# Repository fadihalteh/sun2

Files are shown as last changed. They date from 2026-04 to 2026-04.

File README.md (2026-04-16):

# SunLock Lab Solar Stewart Tracker

<p align="center">
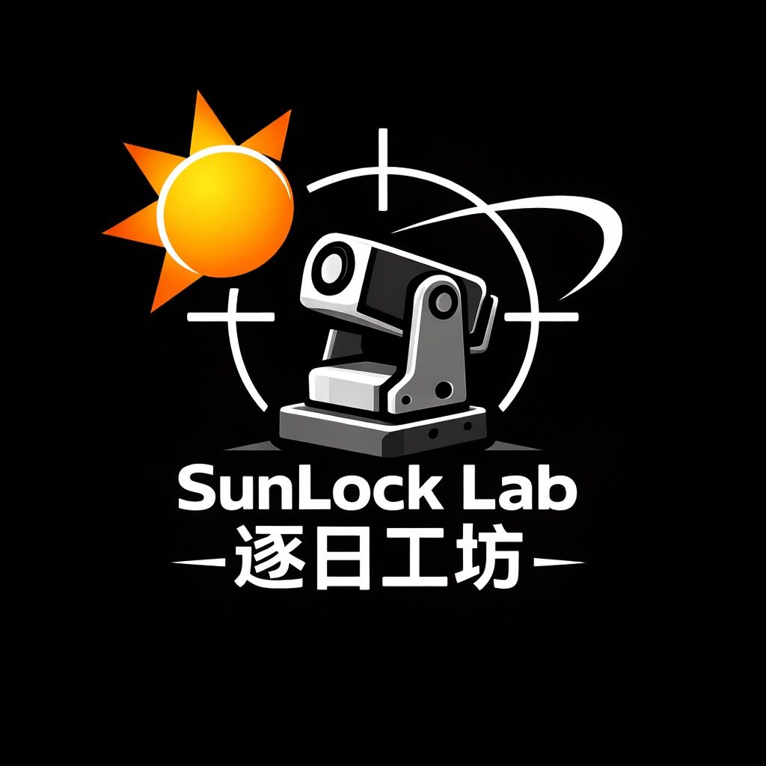
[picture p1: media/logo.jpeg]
SunLock Lab Solar Stewart Tracker
  
</p>
circuitff

https://github.com/user-attachments/assets/e373fa9c-2d9f-4f3f-8f36-7be25adaffa7

[https://www.youtube.com/shorts/J-tgFS92vjE](url)

Real-time embedded **C++17** software for solar tracking using a **3-RRS Stewart-type parallel mechanism** on **Raspberry Pi / Linux**.

This project implements an event-driven pipeline in which camera frames are delivered through callbacks, processed by vision and control modules, converted into platform motion through inverse kinematics, and safely applied to three actuators through a hardware abstraction layer. The runtime is structured around blocking waits, callback-driven stage transitions, bounded queues, and modular components so the software remains responsive, maintainable, testable, and reproducible.

<p align="center">
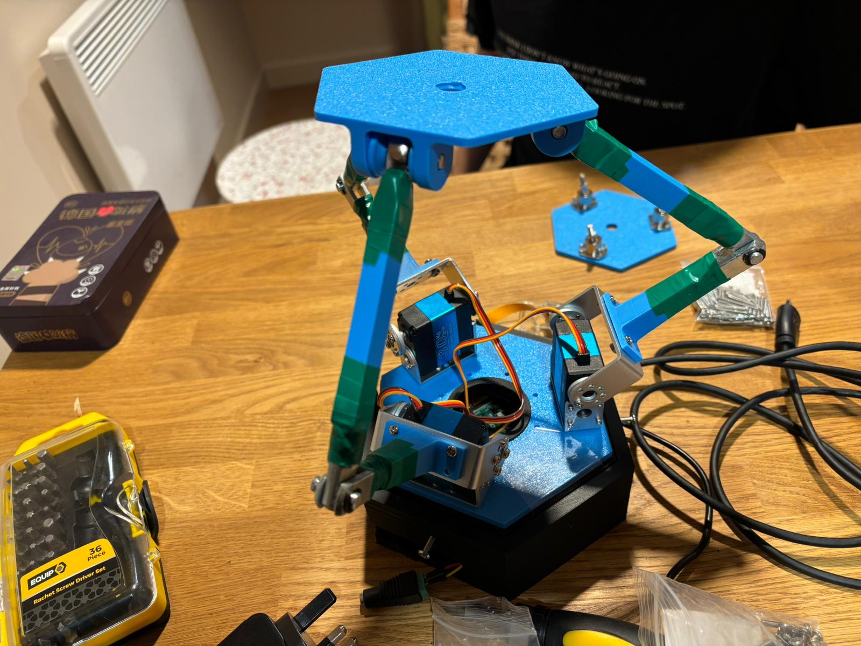
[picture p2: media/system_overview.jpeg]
System Overview
  
</p>
<p align="center">
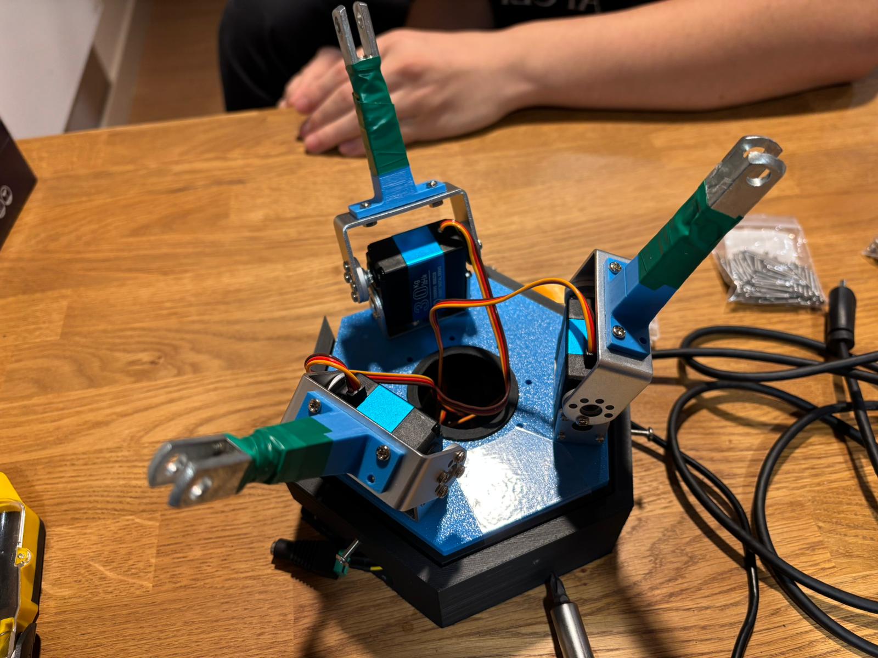
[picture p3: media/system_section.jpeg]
System Section
  
</p>
<p align="center">
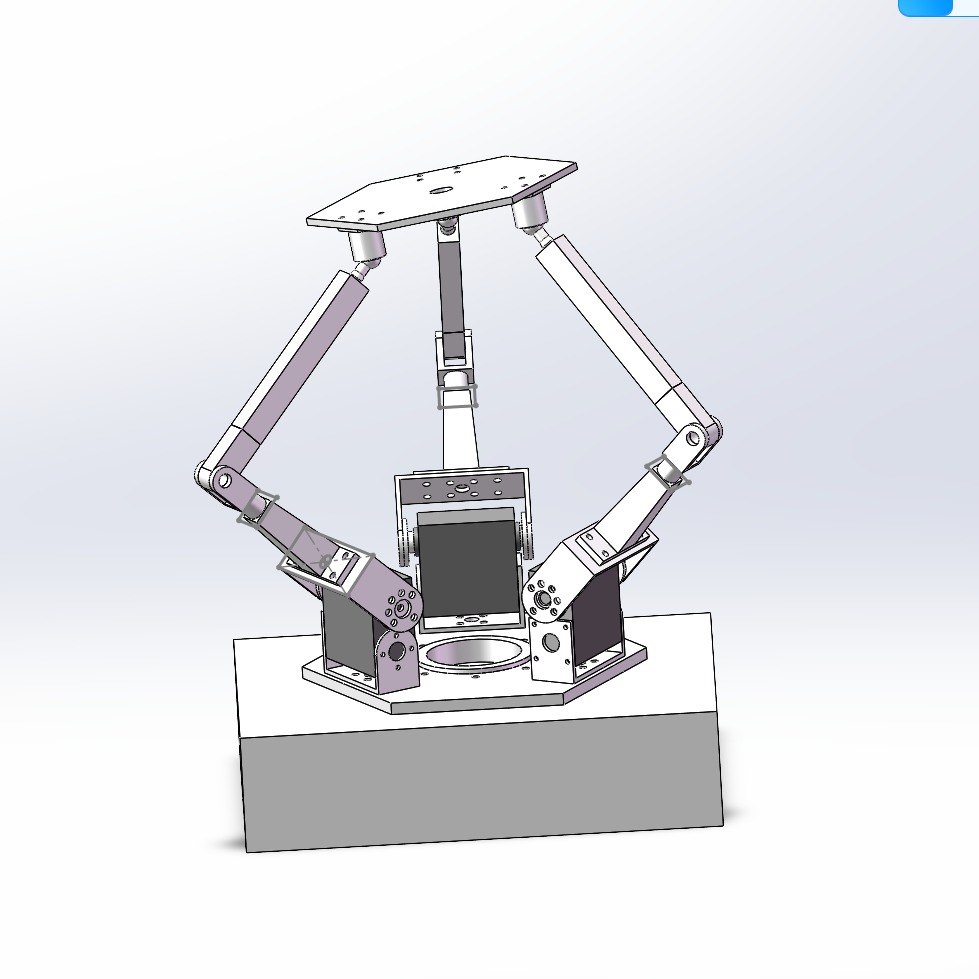
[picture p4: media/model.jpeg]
System Model
  
</p>

---
<p align="center">
  <strong>Explore the full generated developer reference, architecture pages, and API documentation.</strong><br>
  📘 <a href="https://real-time-stewart-solar-tracker.github.io/Solar-Stewart-Tracker/">
    Doxygen Documentation
  </a>
</p>

---
## Table of Contents

- [Social Media](#social-media)
- [Project Overview](#project-overview)
- [Project Management](#project-management)
- [Key Features](#key-features)
- [System Architecture](#system-architecture)
- [Sequence Diagram](#sequence-diagram)
- [Circuit Diagram](#circuit-diagram)
- [Repository Structure](#repository-structure)
- [Bill of Materials](#bill-of-materials)
- [Dependencies](#dependencies)
- [Cloning](#cloning)
- [Building](#building)
- [Running](#running)
- [Running Tests](#running-tests)
- [Realtime Evidence](#realtime-evidence)
- [Documentation](#documentation)
- [Authors and Contributions](#authors-and-contributions)
- [Acknowledgements](#acknowledgements)
- [License](#license)
- [Future Work](#future-work)
- [Last Updated](#last-updated)

---

## Social Media

We actively document the development, testing, and realtime performance of the **Solar Stewart Tracker** to promote transparency, reproducibility, and engagement with the engineering community.

📌 **TikTok (Primary Platform)**  
https://www.tiktok.com/@sunlock.lab_2

Content includes:

- realtime tracking demonstrations
- hardware setup and wiring
- development progress updates
- testing and debugging clips

---

## Project Overview

The **Solar Stewart Tracker** is a Linux userspace realtime embedded system that:

- acquires camera frames from a camera backend
- detects the sun position using image processing
- computes tracking corrections
- converts desired motion into **3-RRS inverse kinematics**
- applies safety shaping before actuation
- drives three servo outputs through a PCA9685 PWM controller

The design goal is not only functional tracking, but tracking implemented in a way that is:

- **event-driven**
- **responsive**
- **modular**
- **testable**
- **reproducible**
- **safe for hardware control**

The main software path is:

**Camera → SunTracker → Controller → ManualImuCoordinator → Kinematics3RRS → ActuatorManager → ServoDriver**

---

## Project Management

Development was tracked through GitHub issues, milestones, branches, pull requests, and tagged releases.

See:
- Issues for feature planning and bug tracking
- Milestones for delivery stages
- Pull requests for reviewed changes
- Releases 
---

## Key Features

- **Realtime event-driven processing**
  - callback-based frame delivery
  - blocking worker threads
  - no busy-wait control loop in the processing pipeline
  - no sleep-based timing in the control path

- **Modular C++17 architecture**
  - `SystemManager` orchestrates the runtime pipeline
  - hardware-facing and processing modules are separated by clear interfaces
  - optional backends and UI layers do not change the core architecture

- **Multiple build and use modes**
  - Linux / Raspberry Pi execution
  - software-only path with simulated camera input
  - headless CLI application
  - optional Qt GUI target

- **Safety-oriented actuation path**
  - actuator clamping
  - optional slew/rate limiting
  - neutral / park behaviour on start and stop
  - explicit handling of low-confidence tracking conditions
  - fault-driven suppression of invalid actuation commands

- **Engineering evidence built into the repository**
  - CMake-based build
  - CTest-integrated automated tests
  - latency measurement exported to artefacts
  - Doxygen-ready source tree
  - structured repository layout by subsystem

---

## System Architecture

<p align="center">
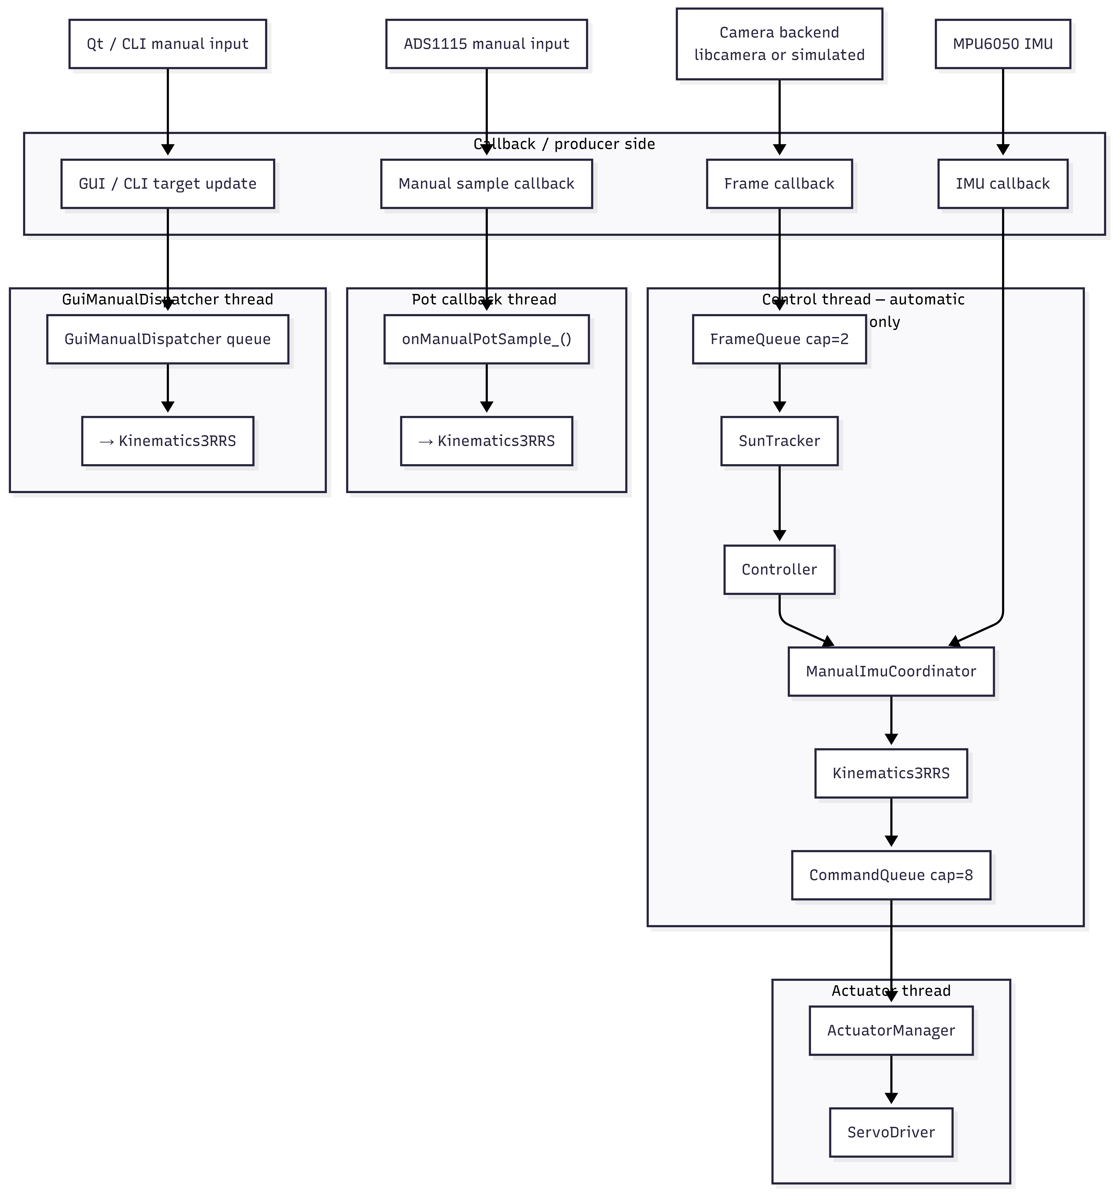
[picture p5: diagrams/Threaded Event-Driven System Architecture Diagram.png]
System Architecture
  
</p>

The repository is organised around a staged runtime pipeline.

### Core Modules

- **ICamera**  
  Abstract camera interface used by the system.

- **LibcameraPublisher**  
  Raspberry Pi / Linux camera backend when `libcamera` is available.

- **SimulatedPublisher**  
  Fallback or simulation camera backend.

- **SystemManager**  
  Top-level orchestrator for state, queues, callbacks, and worker threads.

- **SunTracker**  
  Vision module that finds the bright target and estimates sun position.

- **Controller**  
  Converts tracking error into platform tilt/pan setpoints.

- **ManualImuCoordinator**  
  Coordinates manual input ownership and optional IMU-based correction.

- **Kinematics3RRS**  
  Converts platform setpoints into actuator-space commands.

- **ActuatorManager**  
  Safety shaping layer for command limiting.

- **ServoDriver**  
  Final actuator output layer.

- **LatencyMonitor**  
  Measures timing across the userspace pipeline.

### Threading Model

The runtime is structured as a **multi-threaded, event-driven system** where **blocking I/O is used to wake up threads**, and callbacks propagate data through the processing pipeline.

Separate execution contexts are used for:

- **camera / backend context**: frame acquisition and callback delivery
- **control thread**: vision, control, coordination, and kinematics
- **actuator thread**: safety filtering and output application
- **main / event loop**: application lifecycle and optional UI / event handling

### Queue Policy

Inter-stage communication uses bounded queues with a freshest-data policy:

- **frame queue capacity:** 2
- **command queue capacity:** 8

Both queues use `push_latest(...)`. When a queue is full, the oldest item is discarded before the newest item is inserted. This bounds memory use, prevents unbounded backlog, and keeps the control path biased toward current data rather than stale queued work.

---

## Sequence Diagram

```mermaid
sequenceDiagram
    actor User
    participant Cam as Camera
    participant SM as SystemManager
    participant BC as BackendCoordinator
    participant GMD as GuiManualDispatcher
    participant FQ as FrameQueue
    participant CT as Control thread
    participant ST as SunTracker
    participant C as Controller
    participant MIC as ManualImuCoordinator
    participant K as Kinematics3RRS
    participant CQ as CommandQueue
    participant AT as Actuator thread
    participant AM as ActuatorManager
    participant SD as ServoDriver
    participant ADS as ADS1115
    participant IMU as MPU6050
    participant LM as LatencyMonitor

    User->>SM: start()
    SM->>SD: start()
    SM->>GMD: start()
    SM->>BC: start()
    Note over BC: starts ADS1115 and IMU backends
    SM->>Cam: start()
    SM->>SM: state = SEARCHING / MANUAL

    IMU-->>SM: imu sample callback
    SM->>MIC: updateImuSample(sample)

    rect rgb(245,245,255)
    Note over Cam,SD: Automatic path — control thread only
    Cam-->>SM: FrameEvent callback
    SM->>LM: onCapture(...)
    SM->>FQ: push_latest(frame)

    CT->>FQ: wait_pop()
    FQ-->>CT: FrameEvent
    CT->>ST: onFrame(frame)
    ST-->>CT: SunEstimate callback
    CT->>LM: onEstimate(...)
    CT->>C: onEstimate(estimate)
    C-->>CT: PlatformSetpoint callback
    CT->>LM: onControl(...)
    CT->>MIC: applyImuCorrection(setpoint)
    MIC-->>CT: corrected setpoint
    CT->>K: onSetpoint(setpoint)
    K-->>CT: ActuatorCommand callback
    CT->>CQ: push_latest(command)
    end

    rect rgb(245,255,245)
    Note over ADS,K: Pot manual path — ADS1115 callback thread, independent of camera frames
    ADS-->>SM: ManualPotSample callback
    SM->>MIC: buildManualSetpointFromPot(...)
    MIC-->>SM: PlatformSetpoint
    SM->>MIC: applyImuCorrection(sp)
    MIC-->>SM: corrected setpoint
    SM->>LM: onControl(...)
    SM->>K: onSetpoint(setpoint)
    K-->>SM: ActuatorCommand callback
    SM->>CQ: push_latest(command)
    end

    rect rgb(255,250,240)
    Note over User,K: GUI manual path — GuiManualDispatcher thread, independent of camera frames
    User->>SM: enterManual()
    SM->>SM: state = MANUAL

    User->>SM: setManualSetpoint(tilt, pan)
    SM->>GMD: setSetpoint(tilt, pan)
    Note over GMD: push_latest wakes thread immediately
    GMD->>MIC: buildManualSetpointFromGui(...)
    MIC-->>GMD: PlatformSetpoint
    GMD->>MIC: applyImuCorrection(sp)
    MIC-->>GMD: corrected setpoint
    GMD->>LM: onControl(...)
    GMD->>K: onSetpoint(setpoint)
    K-->>GMD: ActuatorCommand callback
    GMD->>CQ: push_latest(command)

    User->>SM: exitManual()
    SM->>SM: state = SEARCHING
    end

    rect rgb(240,240,240)
    Note over CQ,SD: Actuator path — actuator thread
    AT->>CQ: wait_pop()
    CQ-->>AT: ActuatorCommand
    AT->>AM: onCommand(command)
    AM-->>AT: safe command callback
    AT->>LM: onActuate(...)
    AT->>SD: apply(command)
    end

    User->>SM: stop()
    SM->>Cam: stop()
    SM->>BC: stop()
    SM->>GMD: stop()
    SM->>SD: stop()
    SM->>SM: state = IDLE
```

---

## Circuit Diagram

<p align="center">
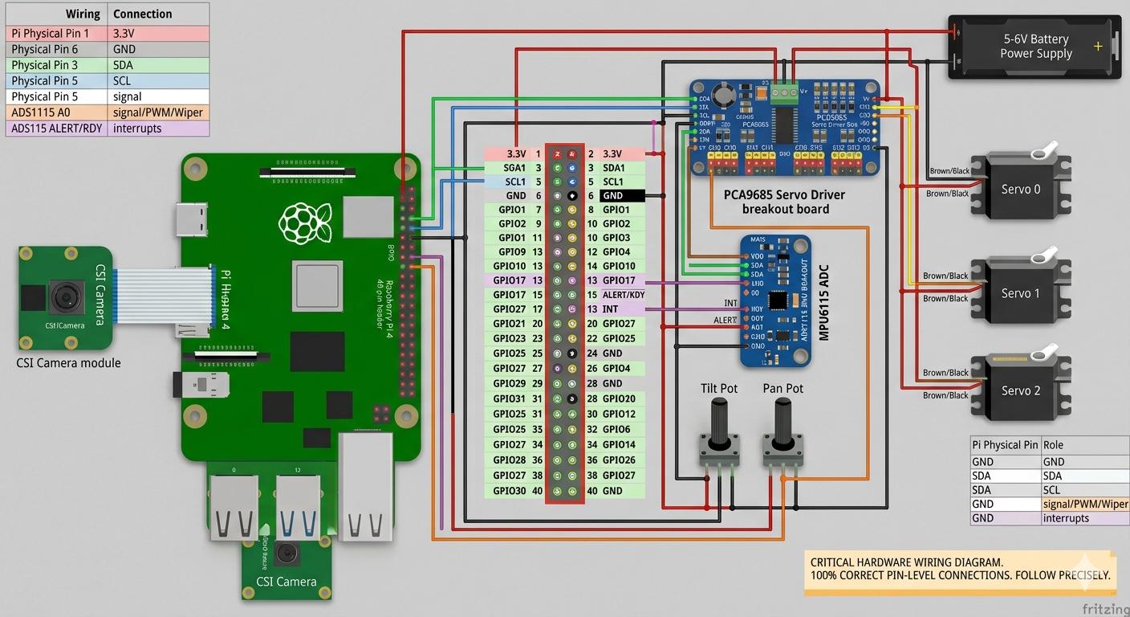
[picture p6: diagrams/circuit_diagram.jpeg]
Circuit Diagram
  
</p>

The hardware setup connects:

- camera through a libcamera-compatible interface
- PCA9685 PWM driver over I2C
- ADS1115 over I2C for manual input
- MPU6050 over I2C for feedback
- three servo motors
- Raspberry Pi acting as the central controller

The PCA9685 generates PWM signals for the servos, while I2C provides communication between the Raspberry Pi, the manual-input ADC, the IMU, and the actuator driver layer.

> **Exact connection mapping:** see [`docs/hardware_connections.md`](docs/hardware_connections.md).  
> This document is the source of truth for physical Raspberry Pi pin numbers, I2C wiring, GPIO interrupt pins, servo channel assignments, potentiometer wiring, and shared-ground requirements.

---

## Repository Structure

```text
Solar-Stewart-Tracker/
├── .github/
│   └── workflows/
├── artefacts/
├── external/
│   ├── libcamera2opencv/
│   └── libgpiod_event_demo/
├── scripts/
├── src/
│   ├── actuators/
│   │   └── tests/
│   ├── app/
│   ├── common/
│   │   └── tests/
│   ├── control/
│   │   └── tests/
│   ├── hal/
│   │   └── tests/
│   ├── qt/
│   ├── sensors/
│   │   └── tests/
│   ├── system/
│   │   └── tests/
│   ├── tests/
│   │   └── support/
│   └── vision/
│       └── tests/
├── CMakeLists.txt
├── CONTRIBUTING.md
├── Doxyfile
└── LICENSE
```

---

## Bill of Materials

### Controller

| Component | Quantity | Cost (£) |
|---|---:|---:|
| Raspberry Pi 5 (8GB) | 1 | 80.00 |

### Sensors and Vision

| Component | Quantity | Cost (£) |
|---|---:|---:|
| IMX219 Camera Module | 1 | 25.00 |

### Actuation and Drive

| Component | Quantity | Cost (£) |
|---|---:|---:|
| PCA9685 PWM Driver | 1 | 12.00 |
| High-Torque Servo (RDS3230 or equivalent) | 3 | 45.00 |
| External 5–6V High-Current Supply | 1 | 20.00 |

### Mechanical and Supporting Components

| Component | Quantity | Cost (£) |
|---|---:|---:|
| Breadboard and Wiring Set | 1 | 10.00 |
| Structural Frame / 3D Printed Parts | 1 | 15.00 |
| Fasteners and Mounts | Assorted | 10.00 |

**Grand Total: £217.00**

---

## Dependencies

### Mandatory

- CMake 3.16 or newer
- C++17 compiler
  - GCC
  - Clang
  - MSVC

### Optional

- **libcamera**  
  Enables the Raspberry Pi camera backend.

- **Qt5 Widgets / Charts**  
  Enables the optional Qt GUI target.

- **OpenCV**  
  Enables optional image-conversion and viewer support where available.

### Linux Packages

#### Minimal build tools

```bash
sudo apt update
sudo apt install -y build-essential cmake git pkg-config
```

#### Optional packages

```bash
sudo apt install -y libcamera-dev
sudo apt install -y qtbase5-dev qtcharts5-dev qt5-qmake
sudo apt install -y libopencv-dev
sudo apt install -y doxygen graphviz
```

---

## Cloning

Clone the repository with all submodules:

```bash
git clone --recurse-submodules https://github.com/Real-Time-Stewart-Solar-Tracker/Solar-Stewart-Tracker.git
cd Solar-Stewart-Tracker
```

If you already cloned without submodules, initialise them with:

```bash
git submodule update --init --recursive
```

### External Repositories Used by This Project

The repository includes these submodules under `external/`:

```text
external/libcamera2opencv
external/libgpiod_event_demo
```

Their configured sources are:

- `external/libcamera2opencv` → `https://github.com/berndporr/libcamera2opencv.git`
- `external/libgpiod_event_demo` → `https://github.com/berndporr/libgpiod_event_demo.git`
---

## Building

### Linux / Raspberry Pi OS

#### Configure

```bash
cmake -S . -B build -G Ninja -DCMAKE_BUILD_TYPE=Release
```

#### Build

```bash
cmake --build build -j
```

### Windows

#### Configure

```bash
cmake -S . -B build
```

#### Build

```bash
cmake --build build --config Release
```

### Optional: Disable OpenCV Auto-Detection

```bash
cmake -S . -B build -G Ninja -DCMAKE_BUILD_TYPE=Release -DSOLAR_TRY_OPENCV=OFF
```

### Optional: Disable libcamera Auto-Detection

```bash
cmake -S . -B build -G Ninja -DCMAKE_BUILD_TYPE=Release -DSOLAR_TRY_LIBCAMERA=OFF
```

### Optional: Enable Hardware-Adjacent Tests

```bash
cmake -S . -B build -G Ninja -DCMAKE_BUILD_TYPE=Release -DSOLAR_ENABLE_HW_TESTS=ON
```

---

## Running

### Core CLI Application

#### Linux

```bash
./build/solar_tracker
```

#### Typical Windows Location

```text
build\Release\solar_tracker.exe
```

### Software-Only Mode

The software-only path uses a simulated camera backend and a non-hardware actuator path for development and testing without the physical platform.

### Optional Qt GUI Application

Built only when Qt support is enabled and found:

```bash
./build/src/qt/solar_tracker_qt
```

#### Typical Windows Location

```text
build\Release\solar_tracker_qt.exe
```

### Hardware Mode

Hardware execution requires:

- libcamera support for the live camera path
- I2C enabled on the host
- PCA9685 connected correctly
- servo power and wiring connected correctly

The system enters `FAULT` if required startup steps fail or mandatory hardware is unavailable.

### Runtime Latency Capture

```bash
./scripts/run_latency.sh
```

This writes latency data to:

```text
artefacts/latency.csv
```

For a fuller command reference, see [`docs/build_and_run.md`](docs/build_and_run.md).

---

## Running Tests

This project integrates tests with **CTest**.

### Run All Registered Tests

#### Linux

```bash
ctest --test-dir build --output-on-failure -LE hw
```

#### Windows

```bash
ctest --test-dir build -C Release --output-on-failure
```

### Convenience Script

```bash
./scripts/test_core.sh
```

### Hardware-Adjacent Test Script

```bash
./scripts/test_pi_hw.sh
```

### Included Automated Test Areas

- SunTracker
- Controller
- ManualInputMapper
- ImuFeedbackMapper
- ImuTiltEstimator
- ActuatorManager
- ThreadSafeQueue
- Kinematics3RRS
- LatencyMonitor
- SystemManager state handling
- PCA9685
- ServoDriver
- MPU6050 publisher
- Linux I2C hardware smoke path

---

## Realtime Evidence

The measured software-side pipeline is:

**Camera → FrameQueue → SunTracker → Controller → ManualImuCoordinator → Kinematics3RRS → ActuatorManager → ServoDriver**

All measurements are taken using monotonic timestamps recorded inside the software pipeline and exported to `artefacts/latency.csv`.

### Latency Results

| Metric | Average (ms) | Minimum (ms) | Maximum (ms) | Jitter (ms) |
|---|---:|---:|---:|---:|
| L_total | 8.369570 | 6.829599 | 14.565364 | 7.735765 |
| L_vision | 8.242496 | 6.755912 | 14.530086 | 7.774174 |
| L_control | 0.014822 | 0.006038 | 0.363637 | 0.357599 |
| L_actuation | 0.112253 | 0.019426 | 3.095969 | 3.076543 |

### Interpretation

- average end-to-end software latency is approximately **8.37 ms**
- worst-case measured software latency is approximately **14.57 ms**
- measured timing remains below a typical **30 Hz** frame period of approximately **33 ms**
- measurements represent the userspace software path only, not full physical actuator motion or mechanical settling time

---

## Documentation

The repository includes a Doxygen configuration file for API documentation generation.

### Generate Doxygen Documentation

```bash
doxygen Doxyfile
```

Open locally at:

```text
docs/html/index.html
```
## Generated Doxygen documentation for the codebase is available here:

- **Project Documentation Website:**  
  https://real-time-stewart-solar-tracker.github.io/Solar-Stewart-Tracker/

### Source Areas Covered by the Documentation Build

- `src/actuators`
- `src/app`
- `src/common`
- `src/control`
- `src/hal`
- `src/sensors`
- `src/system`
- `src/vision`
- `src/qt`

Additional project documentation is provided under `docs/`, including:

- `docs/project_overview.md`
- `docs/system_architecture.md`
- `docs/state_machine.md`
- `docs/realtime_analysis.md`
- `docs/latency_measurement.md`
- `docs/testing.md`
- `docs/solid_justification.md`
- `docs/requirements.md`
- `docs/user_stories_use_cases.md`
- `docs/DEPENDENCIES.md`
- `docs/REPRODUCIBILITY.md`
- `docs/build_and_run.md`
- `docs/hardware_connections.md`

---

## Authors and Contributions

**Fadi Halteh (3127931H)**  
Designed and implemented the event-driven system architecture, including runtime orchestration, state handling, and the bounded queue pipeline. Responsible for integrating the major software stages into the full runtime path.  
Implemented the MPU6050 (IMU) and ADS1115 (manual input) integration within the system, including their event-driven data handling and coordination with the control pipeline.  Also responsible for the system architecture design and creation of the technical diagrams (pipeline, threading, and system architecture).

**Jichao Wang (3137140W)**  
Developed the 3-RRS inverse kinematics model and core application setup, including configuration, factory creation, and application entry structure. Responsible for translating platform setpoints into actuator-space commands.

**Ziming Yan (2429452Y)**  
Developed the vision subsystem and user interface components, including the SunTracker detection pipeline and Qt-based control panel. Integrated visual feedback, overlays, and runtime interaction into the system.

**Tareq A M Almzanin (3139787A)**  
Implemented the control layer translating vision estimates into platform motion, including closed-loop control logic and manual override behaviour. Contributed to the definition of shared data types and the control-side software path.

**Zhenyu Zhu (3099498Z)**  
Implemented the low-level actuator interface including PCA9685 integration and servo control, along with latency measurement instrumentation. Responsible for hardware abstraction and timing analysis across the system pipeline.

*Source: project members document.*

---

## Acknowledgements

We would like to thank:

- Dr. Bernd Porr for guidance in realtime embedded systems and architecture design
- Dr. Chongfeng Wei for software engineering support and project supervision
- the University of Glasgow
- the laboratory, workshop, and technical support staff involved in supporting the project

Their guidance and infrastructure helped shape both the realtime architecture and the engineering process behind this repository.

---

## License

This project is released under the license included in this repository:

```text
LICENSE
```

### External Components and Attribution

The repository also includes or depends on external open-source components. Please credit and use them according to their original licenses.

#### libcamera2opencv
- The libcamera-to-OpenCV wrapper is sourced from Bernd Porr.
- Repository: https://github.com/berndporr/libcamera2opencv

#### libgpiod_event_demo
- GPIO event-driven reference code is sourced from Bernd Porr.
- Repository: https://github.com/berndporr/libgpiod_event_demo

---

## Future Work

Planned or natural next extensions include:

- richer telemetry and live plotting
- enhanced fault handling and recovery strategies
- broader hardware-backed integration testing
- further public-facing project media and demonstration material

---

## Last Updated

April 2026

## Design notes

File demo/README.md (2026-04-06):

# Pipeline Demo

Demonstrates the full automatic tracking pipeline **without any hardware**.

## What it shows

```
SimulatedPublisher → SunTracker → Controller → Kinematics3RRS → stdout
```

A synthetic camera generates 640×480 frames at 30 fps with a bright spot that moves
slowly around the image.  Each stage processes the events in turn and the demo prints
one line per frame showing:

- the detected sun position (pixels) and confidence
- the computed tilt/pan setpoint (radians)
- the resulting servo angles for all 3 actuators (degrees)

## Expected output

```
=== Solar Stewart Tracker — Pipeline Demo ===
Running simulated pipeline for 5 seconds...

[frame    1] sun=( 320.0,  240.0) conf=1.00  →  tilt=+0.000 rad  pan=+0.000 rad  →  servos=[ 90.0,  90.0,  90.0]  status=OK
[frame    2] sun=( 323.1,  241.2) conf=1.00  →  tilt=-0.003 rad  pan=+0.005 rad  →  servos=[ 89.9,  89.8,  90.1]  status=OK
...

=== Demo complete ===
Total frames processed: 150
```

## Requirements

- Same build toolchain as the main project (CMake ≥ 3.16, GCC/Clang with C++17)
- No camera, no I²C, no servos needed

## Build

From the repository root:

```bash
cmake -B build -DCMAKE_BUILD_TYPE=Release
cmake --build build --target pipeline_demo
```

Or add `add_subdirectory(demo)` to the root `CMakeLists.txt`
and rebuild normally.

## Run

```bash
./build/demo/pipeline_demo
```

The demo runs for 5 seconds and exits automatically.

## What to look for

| What you see | What it means |
|---|---|
| `conf=0.00` for the first few frames | The spot starts at centre — zero error, zero confidence needed |
| `tilt`/`pan` grow as the spot moves off-centre | The controller is reacting to the image error |
| `servos` values changing | Kinematics is solving the inverse-kinematics in real time |
| `status=DEGRADED` (if it appears) | The IK solver hit a geometry limit and fell back to the last valid command |

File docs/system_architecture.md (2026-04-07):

# System Architecture

## Overview

The system is structured as a staged, event-driven pipeline in Linux userspace. Frame acquisition, tracking, control, kinematic mapping, and actuator output are separated into distinct classes so that each stage has a clear responsibility and a bounded interface. This is consistent with the taught architecture of sensor events propagating through callbacks and typed data transformations to control outputs.

The implemented automatic processing path is:

**ICamera → SunTracker → Controller → ManualImuCoordinator → Kinematics3RRS → ActuatorManager → ServoDriver**

`SystemManager` orchestrates this pipeline and manages runtime state. `BackendCoordinator` owns hardware backend lifecycle. `GuiManualDispatcher` provides the event-driven GUI manual path. `SystemFactory` assembles the runtime graph.

This class structure is stronger than a monolithic alternative because it separates:

- sensor acquisition from estimation
- estimation from control
- control from mechanism-specific mapping
- mechanism mapping from actuator safety conditioning
- actuator conditioning from final hardware output
- runtime orchestration from backend implementation details

That separation improves maintainability, reduces coupling, and makes the realtime event flow explicit.

---

## Architectural Rationale

The core design decision is to preserve a forward-only event path through specialised classes instead of building one large tracker class. In this repository, each stage transforms one well-defined form of data into the next.

For automatic tracking:

- the camera backend emits frames
- the tracker estimates target position and confidence
- the controller converts that estimate into a platform command
- the manual/IMU coordination layer applies optional correction
- the kinematics layer maps platform motion into actuator-space commands
- the actuator manager applies command conditioning and output safety policy
- the servo driver performs final calibrated output to the physical device

For manual mode, both input paths are independently event-driven:

**Pot-driven manual:** ADS1115 ALERT/RDY GPIO edge → `onManualPotSample_()` → setpoint built and dispatched directly to `Kinematics3RRS`. Timing is driven by the ADS1115 conversion rate, independent of camera frames.

**GUI-driven manual:** Qt slider → `setManualSetpoint()` → `GuiManualDispatcher::setSetpoint()` → push to bounded queue → `GuiManualDispatcher` worker thread wakes immediately → setpoint built via `ManualImuCoordinator` and dispatched directly to `Kinematics3RRS`. Timing is driven by operator input rate, independent of camera frames.

The control thread handles only the automatic path. It is not involved in either manual path.

This staged structure is appropriate because the taught approach is event-driven userspace code built around callbacks, blocking waits, and clean class interfaces rather than polling loops or single-threaded delay-based control.

---

## Diagram 1 — UML Class Diagram

```mermaid
classDiagram
direction LR

class SystemManager {
  +start() bool
  +stop() void
  +state() TrackerState
  +enterManual() void
  +exitManual() void
  +setManualSetpoint(tilt_rad, pan_rad) void
  +setTrackerThreshold(thr) void
  +setManualCommandSource(src) void
  +registerFrameObserver(cb) void
  +registerEstimateObserver(cb) void
  +registerSetpointObserver(cb) void
  +registerCommandObserver(cb) void
  +registerLatencyObserver(cb) void
  -onFrame_(fe) void
  -controlLoop_() void
  -actuatorLoop_() void
  -setState_(s) void
  -applyNeutralOnce_() void
  -applyParkOnce_(servo_deg) void
}

class BackendCoordinator {
  +start(log) StartResult
  +stop() void
}

class GuiManualDispatcher {
  +start() void
  +stop() void
  +setSetpoint(tilt_rad, pan_rad) void
  +registerSetpointObserver(cb) void
}

class ICamera {
  <<interface>>
  +registerFrameCallback(cb) void
  +start() bool
  +stop() void
  +isRunning() bool
}

class LibcameraPublisher
class SimulatedPublisher
ICamera <|.. LibcameraPublisher
ICamera <|.. SimulatedPublisher

class ThreadSafeQueue~T~ {
  +ThreadSafeQueue(capacity)
  +wait_pop() optional~T~
  +push_latest(item) bool
  +stop() void
  +reset() void
  +clear() void
}

class SunTracker {
  +registerEstimateCallback(cb) void
  +setThreshold(thr) void
  +onFrame(fe) void
}

class Controller {
  +registerSetpointCallback(cb) void
  +onEstimate(est) void
}

class Kinematics3RRS {
  +registerCommandCallback(cb) void
  +onSetpoint(sp) void
}

class ActuatorManager {
  +registerSafeCommandCallback(cb) void
  +onCommand(cmd) void
}

class ServoDriver {
  +start() bool
  +stop() void
  +apply(cmd) void
}

class LatencyMonitor {
  +onCapture(frame_id, t) void
  +onEstimate(frame_id, t) void
  +onControl(frame_id, t) void
  +onActuate(frame_id, t) void
}

class ManualImuCoordinator {
  +setManualCommandSource(src) void
  +manualCommandSource() ManualCommandSource
  +updateImuSample(sample) void
  +applyImuCorrection(sp) PlatformSetpoint
  +buildManualSetpointFromPot(sample, state, frame_id, t, sp) bool
  +buildManualSetpointFromGui(tilt, pan, state, frame_id, t, sp) bool
}

class ADS1115ManualInput {
  +registerCallback(cb) void
  +start() bool
  +stop() void
}

class Mpu6050Publisher {
  +registerEventCallback(cb) void
  +start() bool
  +stop() void
}

SystemManager o-- ICamera
SystemManager o-- SunTracker
SystemManager o-- Controller
SystemManager o-- Kinematics3RRS
SystemManager o-- ActuatorManager
SystemManager o-- ServoDriver
SystemManager o-- LatencyMonitor
SystemManager o-- ManualImuCoordinator
SystemManager o-- BackendCoordinator
SystemManager o-- GuiManualDispatcher
BackendCoordinator o-- ADS1115ManualInput
SystemManager o-- Mpu6050Publisher

SystemManager o-- ThreadSafeQueue~FrameEvent~ : frame_q_ cap=2
SystemManager o-- ThreadSafeQueue~ActuatorCommand~ : cmd_q_ cap=8

ICamera ..> FrameEvent : emits via callback
SunTracker ..> SunEstimate : emits via callback
Controller ..> PlatformSetpoint : emits via callback
Kinematics3RRS ..> ActuatorCommand : emits via callback
ActuatorManager ..> ActuatorCommand : emits safe callback
ADS1115ManualInput ..> ManualPotSample : emits via callback
Mpu6050Publisher ..> ImuSample : emits via callback
ManualImuCoordinator ..> PlatformSetpoint : adjusts / builds
```

---

## Diagram 2.1 — Sequence Diagram — Automatic Runtime Pipeline

```mermaid
sequenceDiagram
autonumber

participant Cam as Camera backend
participant SM as SystemManager
participant FQ as FrameQueue cap=2
participant CT as Control thread
participant ST as SunTracker
participant C as Controller
participant MIC as ManualImuCoordinator
participant K as Kinematics3RRS
participant CQ as CommandQueue cap=8
participant AT as Actuator thread
participant AM as ActuatorManager
participant SD as ServoDriver
participant LM as LatencyMonitor

SM->>Cam: registerFrameCallback(onFrame_)
SM->>ST: registerEstimateCallback(...)
SM->>C: registerSetpointCallback(...)
SM->>K: registerCommandCallback(...)
SM->>AM: registerSafeCommandCallback(...)
SM->>SD: start()
SM->>Cam: start()
SM->>SM: setState(SEARCHING)

Cam-->>SM: FrameCallback(FrameEvent)
SM->>LM: onCapture(frame_id, t_capture)
SM->>FQ: push_latest(FrameEvent)

CT->>FQ: wait_pop()
FQ-->>CT: FrameEvent
CT->>ST: onFrame(FrameEvent)

ST-->>CT: EstimateCallback(SunEstimate)
CT->>LM: onEstimate(frame_id, t_estimate)

alt confidence >= threshold
  CT->>SM: setState(TRACKING)
else confidence < threshold
  CT->>SM: setState(SEARCHING)
end

CT->>C: onEstimate(SunEstimate)
C-->>CT: SetpointCallback(PlatformSetpoint)
CT->>LM: onControl(frame_id, t_control)

CT->>MIC: applyImuCorrection(PlatformSetpoint)
MIC-->>CT: corrected PlatformSetpoint

CT->>K: onSetpoint(corrected PlatformSetpoint)
K-->>CT: CommandCallback(ActuatorCommand)
CT->>CQ: push_latest(ActuatorCommand)

AT->>CQ: wait_pop()
CQ-->>AT: ActuatorCommand
AT->>AM: onCommand(ActuatorCommand)

AM-->>AT: SafeCommandCallback(ActuatorCommand)
AT->>LM: onActuate(frame_id, t_actuate)
AT->>SD: apply(ActuatorCommand)
```

---

## Diagram 2.2 — Sequence Diagram — Manual Input + IMU Update Paths

```mermaid
sequenceDiagram
autonumber

participant ADS as ADS1115ManualInput
participant IMU as Mpu6050Publisher
participant User as Qt / CLI User
participant SM as SystemManager
participant BC as BackendCoordinator
participant GMD as GuiManualDispatcher
participant MIC as ManualImuCoordinator
participant K as Kinematics3RRS
participant CQ as CommandQueue cap=8
participant AT as Actuator thread
participant AM as ActuatorManager
participant SD as ServoDriver
participant LM as LatencyMonitor

Note over BC,ADS: BackendCoordinator owns ADS1115 and IMU lifecycle
BC->>ADS: start()
BC->>IMU: start()

IMU-->>SM: IMU callback(sample)
SM->>MIC: updateImuSample(sample)

User->>SM: enterManual()
SM->>MIC: setManualCommandSource(Pot or GUI)
SM->>SM: setState(MANUAL)

alt Pot-controlled manual mode — ADS1115 ALERT/RDY edge driven
  ADS-->>SM: ManualPotSample callback
  SM->>MIC: buildManualSetpointFromPot(sample, state, id, t, sp)
  MIC-->>SM: PlatformSetpoint
  SM->>MIC: applyImuCorrection(sp)
  MIC-->>SM: corrected PlatformSetpoint
  SM->>LM: onControl(frame_id, t_control)
  SM->>K: onSetpoint(corrected PlatformSetpoint)
  Note over SM,K: Dispatched directly in ADS1115 callback — no frame dependency
else GUI-controlled manual mode — operator input rate driven
  User->>SM: setManualSetpoint(tilt, pan)
  SM->>GMD: setSetpoint(tilt, pan)
  Note over GMD: push_latest to bounded queue — wakes immediately
  GMD->>MIC: buildManualSetpointFromGui(tilt, pan, state, id, t, sp)
  MIC-->>GMD: PlatformSetpoint
  GMD->>MIC: applyImuCorrection(sp)
  MIC-->>GMD: corrected PlatformSetpoint
  GMD->>LM: onControl(frame_id, t_control)
  GMD->>K: onSetpoint(corrected PlatformSetpoint)
  Note over GMD,K: Dispatched from GuiManualDispatcher thread — no frame dependency
end

K-->>K: CommandCallback(ActuatorCommand)
K->>CQ: push_latest(ActuatorCommand)

AT->>CQ: wait_pop()
CQ-->>AT: ActuatorCommand
AT->>AM: onCommand(ActuatorCommand)
AM-->>AT: SafeCommandCallback(ActuatorCommand)
AT->>LM: onActuate(frame_id, t_actuate)
AT->>SD: apply(ActuatorCommand)

User->>SM: exitManual()
SM->>SM: setState(SEARCHING)
```

---

## Diagram 3 — Component Diagram

```mermaid
flowchart LR
  subgraph EntryPoints["Entry Points"]
    CLI["solar_tracker (CLI)"]
    QT["solar_tracker_qt (Qt UI)"]
  end

  subgraph Core["Core Realtime Pipeline"]
    SM["SystemManager"]
    FQ["FrameQueue cap=2<br/>ThreadSafeQueue&lt;FrameEvent&gt;"]
    CQ["CommandQueue cap=8<br/>ThreadSafeQueue&lt;ActuatorCommand&gt;"]
    ST["SunTracker"]
    C["Controller"]
    MIC["ManualImuCoordinator"]
    K["Kinematics3RRS"]
    AM["ActuatorManager"]
    SD["ServoDriver"]
    LM["LatencyMonitor"]
  end

  subgraph Vision["Camera Backends"]
    ICam["ICamera"]
    Lib["LibcameraPublisher"]
    Sim["SimulatedPublisher"]
  end

  subgraph ManualInput["Manual Input"]
    ADS["ADS1115ManualInput<br/>ALERT/RDY GPIO edge"]
    GMD["GuiManualDispatcher<br/>dedicated thread + queue"]
    BC["BackendCoordinator<br/>owns ADS1115 + IMU"]
  end

  subgraph ImuFeedback["IMU Feedback"]
    MPU["Mpu6050Publisher"]
  end

  CLI --> SM
  QT --> SM

  Lib -- implements --> ICam
  Sim -- implements --> ICam
  ICam -->|Frame callback| SM

  SM --> FQ
  FQ -->|wait_pop in control thread| ST
  ST --> C
  C --> MIC
  MIC --> K
  K --> CQ
  CQ -->|wait_pop in actuator thread| AM
  AM --> SD

  ADS -->|manual sample callback| SM
  SM -->|dispatch direct to K| K
  QT -->|setManualSetpoint| SM
  SM -->|setSetpoint| GMD
  GMD -->|dispatch direct to K| K
  MPU -->|IMU callback| SM
  SM --> MIC

  SM --> LM
```

---

## Diagram 4 — Threaded Event Architecture

```mermaid
flowchart TB
  CAM["Camera backend<br/>libcamera or simulated"]
  ADS["ADS1115 manual input"]
  MPU["MPU6050 IMU"]
  UI["Qt / CLI manual input"]

  subgraph T1["Callback / producer side"]
    CAMCB["Frame callback"]
    ADSCB["Manual sample callback"]
    MPUCB["IMU callback"]
    UICB["GUI / CLI target update"]
  end

  subgraph T2["Control thread — automatic path only"]
    FQ["FrameQueue cap=2"]
    ST["SunTracker"]
    CTRL["Controller"]
    MIC["ManualImuCoordinator"]
    KIN["Kinematics3RRS"]
    CQ["CommandQueue cap=8"]
  end

  subgraph T4["Pot callback thread (ADS1115)"]
    ADSCB2["onManualPotSample_()"]
    POTK["→ Kinematics3RRS"]
  end

  subgraph T5["GuiManualDispatcher thread"]
    GUIQ["GuiManualDispatcher queue"]
    GUIK["→ Kinematics3RRS"]
  end

  subgraph T3["Actuator thread"]
    ACT["ActuatorManager"]
    SERVO["ServoDriver"]
  end

  CAM --> CAMCB --> FQ
  FQ --> ST --> CTRL --> MIC --> KIN --> CQ
  ADS --> ADSCB --> ADSCB2 --> POTK
  UI --> UICB --> GUIQ --> GUIK
  MPU --> MPUCB --> MIC
  CQ --> ACT --> SERVO
```

---

## Component Responsibilities

### SystemManager

Coordinates runtime execution, manages threads, processes incoming events, and controls system state. Manual timing is fully delegated: potentiometer commands dispatch directly from the ADS1115 callback, and GUI commands dispatch from `GuiManualDispatcher`. The control thread handles only the automatic pipeline.

### BackendCoordinator

Owns the lifecycle of optional hardware backends: ADS1115 manual input and MPU-6050/ICM-20600 IMU. Starts, stops, and owns I2C/GPIO resources independently of pipeline orchestration.

### GuiManualDispatcher

Owns a dedicated worker thread and bounded freshest-data queue for GUI manual setpoints. When `setManualSetpoint()` is called, the dispatcher wakes immediately and dispatches the setpoint to `Kinematics3RRS` without depending on camera-frame timing.

### ICamera and Camera Backends

Provide frame acquisition. Multiple implementations can be used without affecting downstream processing.

### SunTracker

Processes image data and produces a target estimate including position and confidence.

### Controller

Transforms the target estimate into a platform-level motion command.

### ManualImuCoordinator

Handles manual input ownership and optional IMU-based adjustments. It builds manual setpoints and applies IMU correction where allowed by mode/source policy.

### Kinematics3RRS

Maps platform motion commands into actuator-specific commands based on mechanism geometry.

### ActuatorManager

Applies conditioning to actuator commands such as clamping and rate limiting to ensure safe output.

### ServoDriver and PCA9685

Convert actuator commands into hardware signals and communicate with the PWM controller.

### Input Devices

- `ADS1115ManualInput` provides potentiometer-based manual control input
- `Mpu6050Publisher` provides IMU data for orientation feedback

---

## Architectural Summary

The system is built as a pipeline of independent processing stages connected through well-defined interfaces. Each stage transforms data and passes it forward without direct knowledge of internal details of other components.

This structure enables:

- predictable data flow
- clear separation between computation and hardware access
- safe multi-threaded execution
- straightforward extension and modification of individual stages

The inter-thread queues are intentionally bounded:

- Frame queue capacity is small (2) to minimise latency and prevent stale frames accumulating.
- Command queue capacity is larger (8) to absorb short bursts without dropping actuator updates prematurely.

Both queues use a latest-wins policy, ensuring that the system prioritises current data while maintaining bounded memory and predictable behaviour.

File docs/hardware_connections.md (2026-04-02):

# EXACT CONNECTIONS 

---

##  Raspberry Pi Pins (PHYSICAL)

| Physical Pin | Signal | Connection |
|---|---|---|
| Pin 1 | 3.3V | PCA9685 VCC, ADS1115 VDD, MPU6050 VCC |
| Pin 3 | GPIO2 (SDA1) | PCA9685 SDA, ADS1115 SDA, MPU6050 SDA |
| Pin 5 | GPIO3 (SCL1) | PCA9685 SCL, ADS1115 SCL, MPU6050 SCL |
| Pin 6 | GND | ALL module grounds + external supply ground |
| Pin 11 | GPIO17 | ADS1115 ALERT/RDY |
| Pin 13 | GPIO27 | MPU6050 INT |

---

##  PCA9685 Connections

| Pin | Connects To |
|-----|---|
| VCC | Raspberry Pi Pin 1 (3.3V) |
| GND | Raspberry Pi Pin 6 (GND) |
| SDA | Raspberry Pi Pin 3 (GPIO2 / SDA1) |
| SCL | Raspberry Pi Pin 5 (GPIO3 / SCL1) |
| V+  | External 5–6V power supply (+) |

### Servo Outputs

| Channel | Connects To |
|---|---|
| CH0 | Servo 0 signal |
| CH1 | Servo 1 signal |
| CH2 | Servo 2 signal |

---

## ADS1115 Connections

| Pin | Connects To |
|-----|---|
| VDD | Raspberry Pi Pin 1 (3.3V) |
| GND | Raspberry Pi Pin 6 (GND) |
| SDA | Raspberry Pi Pin 3 (GPIO2 / SDA1) |
| SCL | Raspberry Pi Pin 5 (GPIO3 / SCL1) |
| ALERT/RDY | Raspberry Pi Pin 11 (GPIO17) |

###  Analog Inputs

| Channel | Source |
|---|---|
| A0 | Tilt potentiometer (wiper) |
| A1 | Pan potentiometer (wiper) |

---

##  MPU6050 Connections

| Pin | Connects To |
|-----|---|
| VCC | Raspberry Pi Pin 1 (3.3V) |
| GND | Raspberry Pi Pin 6 (GND) |
| SDA | Raspberry Pi Pin 3 (GPIO2 / SDA1) |
| SCL | Raspberry Pi Pin 5 (GPIO3 / SCL1) |
| INT | Raspberry Pi Pin 13 (GPIO27) |

---

##  Servo Wiring

Each servo has 3 wires:

| Servo Wire | Connects To |
|---|---|
| Red (Power) | External 5–6V power supply (+) |
| Brown / Black (GND) | External supply GND (shared with Pi GND) |
| Yellow / Orange (Signal) | PCA9685 channel (CH0 / CH1 / CH2) |

---

##  Potentiometers (2 Units)

Each potentiometer has 3 pins:

| Potentiometer Pin | Connects To |
|---|---|
| One end | Raspberry Pi Pin 1 (3.3V) |
| Other end | Raspberry Pi Pin 6 (GND) |
| Middle (Wiper) | ADS1115 A0 (tilt) or A1 (pan) |

---

##  External Power Supply

| Pin | Connects To |
|-----|---|
| +V (5–6V) | PCA9685 V+ and all servo power pins |
| GND | Common ground (connected to Raspberry Pi GND) |

---

##  CSI Camera

| Connection | Description |
|---|---|
| CSI Ribbon Cable | Connects directly to Raspberry Pi CSI port |
| GPIO Usage | None |

---

#  CRITICAL ELECTRICAL RULES

- All grounds MUST be connected together (common ground)
- I2C bus is shared:
  - SDA → PCA9685, ADS1115, MPU6050
  - SCL → PCA9685, ADS1115, MPU6050
- DO NOT swap SDA and SCL
- DO NOT power servos from Raspberry Pi
- DO NOT connect 5–6V to any Raspberry Pi GPIO pin
- PCA9685 has TWO power domains:
  - VCC → 3.3V (logic)
  - V+ → 5–6V (servos)

---

#  SYSTEM SUMMARY

- Raspberry Pi controls system logic
- I2C bus connects sensors and driver:
  - PCA9685 (actuation)
  - ADS1115 (manual input)
  - MPU6050 (feedback)
- External supply powers servos only
- Interrupt-driven design:
  - ADS1115 → GPIO17
  - MPU6050 → GPIO27

---

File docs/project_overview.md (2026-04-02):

# Project Overview

## Project Identity

This repository implements a real-time Stewart-platform solar tracker on Raspberry Pi/Linux userspace.

The system processes a camera stream, detects the dominant light source, converts image-space error into platform tilt and pan setpoints, maps those setpoints to actuator commands, applies output conditioning, and drives the platform through a servo-based actuation system.

---

## End-to-End Behaviour

The automatic runtime pipeline is:

```text
Camera → SunTracker → Controller → ManualImuCoordinator → Kinematics3RRS → ActuatorManager → ServoDriver
```

This staged flow is orchestrated in `src/system/SystemManager.cpp`.

Manual mode uses the same downstream actuation path.

```text
GUI valueChanged / ADS1115 callback
→ store latest manual state
→ control thread tick
→ ManualImuCoordinator builds manual setpoint
→ Kinematics3RRS → ActuatorManager → ServoDriver
```

This means manual mode is continuous without turning the GUI into the timing source.

---

## What the repo  Supports

The  repository  supports:

- automatic tracking
- manual mode from GUI or potentiometers
- IMU observation or live correction path
- headless Linux event-loop execution
- Qt GUI execution
- simulated camera fallback
- software unit tests
- Raspberry Pi hardware smoke-test workflow
- latency CSV generation
- Doxygen generation
- release packaging workflow

---

## Main Repository Subsystems

### Runtime and composition
- `src/main.cpp`
- `src/qt/main_qt.cpp`
- `src/app/Application.cpp`
- `src/app/LinuxEventLoop.cpp`
- `src/app/CliController.cpp`
- `src/app/SystemFactory.cpp`
- `src/app/AppConfig.cpp`

### Vision and control
- `src/vision/SunTracker.cpp`
- `src/control/Controller.cpp`
- `src/control/Kinematics3RRS.cpp`
- `src/control/ManualInputMapper.cpp`
- `src/control/ImuFeedbackMapper.cpp`
- `src/control/ImuTiltEstimator.cpp`
- `src/control/ManualImuCoordinator.cpp`

### Actuation
- `src/actuators/ActuatorManager.cpp`
- `src/actuators/ServoDriver.cpp`
- `src/actuators/PCA9685.cpp`

### Hardware/backend support
- `src/sensors/SimulatedPublisher.cpp`
- `src/sensors/LibcameraPublisher.cpp`
- `src/sensors/manual/ADS1115ManualInput.cpp`
- `src/sensors/imu/Mpu6050Publisher.cpp`
- `src/hal/LinuxI2CDevice.cpp`

### System orchestration
- `src/system/SystemManager.cpp`
- `src/system/SystemManager.hpp`
- `src/system/TrackerState.hpp`

### GUI
- `src/qt/MainWindow.cpp`
- `src/qt/MainWindow.hpp`

---

## Runtime Modes and Backends

Configuration supports:

- `CameraBackend::Simulated`
- `CameraBackend::Libcamera`
- `StartupMode::Auto`
- `StartupMode::Manual`
- `ManualInputBackend::ADS1115`
- `ImuBackend::Mpu6050Gpio`
- `ImuFeedbackMode::Disabled`
- `ImuFeedbackMode::Shadow`
- `ImuFeedbackMode::Live`

Manual mode also distinguishes command ownership between:

- `ManualCommandSource::Gui`
- `ManualCommandSource::Pot`

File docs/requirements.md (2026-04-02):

# Requirements

## Purpose

This document defines the requirements implemented in the  repository . All requirements are derived directly from the  source tree, `CMakeLists.txt`, `src/app/AppConfig.cpp`, and the hardware defaults in `src/app/AppConfig.hpp`.

---

## 1. Platform Requirements

| Requirement | Source |
|---|---|
| Linux userspace execution | `LinuxEventLoop`, `signalfd`, `timerfd`, `eventfd`, `poll()` |
| C++17 standard | `CMakeLists.txt`: `CMAKE_CXX_STANDARD 17` |
| CMake 3.16 or newer | `CMakeLists.txt`: `cmake_minimum_required(VERSION 3.16)` |
| Raspberry Pi (arm64) target for hardware mode | Pi hardware workflow / scripts |
| I2C bus 1 available (`/dev/i2c-1`) | `AppConfig.cpp`: hardware defaults use `i2c_bus = 1` |
| GPIO chip 0 available | `AppConfig.cpp`: `gpio_chip_index = 0` for ADS1115 and MPU6050 |
| `libgpiod` available | build / workflow dependency |
| Optional: Qt5 Widgets + Charts | `src/qt/CMakeLists.txt` |
| Optional: OpenCV + libcamera | top-level CMake option path |

---

## 2. Functional Requirements

### FR1 — Frame acquisition via abstract camera interface

The system shall acquire frames through `ICamera`, a pure virtual interface defining `registerFrameCallback()`, `start()`, `stop()`, and `isRunning()`.

Two concrete implementations shall be provided:

- `SimulatedPublisher` — always available; paces frames via `timerfd`-based `poll()`
- `LibcameraPublisher` — available when both libcamera and OpenCV are found at configure time

The active camera backend is selected by `SystemFactory`.

### FR2 — Bright-target detection and centroid estimation

`SunTracker` shall process one `FrameEvent` and produce one `SunEstimate` containing:

- weighted centroid position (`cx`, `cy`) in pixels
- confidence value in range `[0,1]`

Detection shall use a configurable brightness threshold and minimum bright-pixel count. Supported pixel formats are `Gray8`, `RGB888`, and `BGR888`, with padded-stride frames handled correctly.

### FR3 — Image-space error to platform setpoint conversion

`Controller` shall convert a `SunEstimate` into a `PlatformSetpoint` (tilt and pan in radians) using proportional control with configurable gains, deadband, and output clamps. Estimates below the configured confidence threshold suppress motion.

### FR4 — Platform setpoint to actuator command via 3-RRS kinematics

`Kinematics3RRS` shall map a `PlatformSetpoint` to an `ActuatorCommand` containing three actuator targets in degrees.

If the inverse-kinematics solution is geometrically invalid, the system shall either fall back to the last valid command or surface an invalid configuration state that triggers FAULT handling.

### FR5 — Per-channel output safety conditioning

`ActuatorManager` shall apply per-channel clamping and optional slew/rate limiting before hardware output.

### FR6 — Servo hardware output via PCA9685

`ServoDriver` shall output conditioned actuator commands through the PCA9685 PWM controller and support startup policies including `LogOnly`, `PreferHardware`, and `RequireHardware`.

### FR7 — Manual control via potentiometer input

`ADS1115ManualInput` shall provide a manual-input path using ADS1115 plus ALERT/RDY GPIO wakeup.

`ManualInputMapper` shall convert raw voltages to bounded setpoints with deadband and optional inversion.

The potentiometer callback shall update the latest manual sample, but downstream manual actuation shall be owned by the control thread rather than driven directly from the callback.

### FR8 — IMU tilt measurement and optional correction

`Mpu6050Publisher` shall provide an IMU backend using I2C and a GPIO data-ready interrupt.

`ImuTiltEstimator` and `ImuFeedbackMapper` shall compute and optionally apply correction offsets.

Modes include:

- Disabled
- Shadow
- Live

Failure handling depends on mode.

### FR9 — Headless CLI runtime

`LinuxEventLoop` shall provide a runtime using blocking `poll()` over:

- `signalfd`
- `timerfd`
- stdin

CLI commands include:

- `manual`
- `auto`
- `set <tilt> <pan>`
- `threshold <value>`
- `quit`
- `help`

### FR10 — Qt GUI runtime

`solar_tracker_qt` shall provide a GUI with:

- control buttons
- camera preview
- status display
- charts for actuator commands, ADC, and IMU
- manual sliders for GUI-set manual control

Qt timers are used for GUI refresh, not as the timing source for control.

GUI manual mode shall update the stored manual target continuously while the slider is dragged. Continuous manual actuation shall still be performed by the control thread.

### FR11 — Explicit runtime state machine

The system shall implement an explicit state machine with:

- IDLE
- STARTUP
- NEUTRAL
- SEARCHING
- TRACKING
- MANUAL
- STOPPING
- FAULT

Transitions shall be explicit and observable.

### FR12 — Per-frame latency measurement

`LatencyMonitor` shall record timestamps at key pipeline stages and compute per-frame latency metrics. Summary statistics shall be printed on shutdown. CSV export shall be supported via environment configuration.

### FR13 — Software test execution

The build system shall support a software test suite runnable via CTest without requiring physical hardware.

Test binaries shall be executable directly. Additional command-line interfaces may exist but are not assumed to be uniform across all tests.

### FR14 — Hardware smoke test execution

The build system shall support hardware-adjacent tests via `-DSOLAR_ENABLE_HW_TESTS=ON`, runnable on a Raspberry Pi.

Hardware-dependent tests shall support safe skipping when hardware is unavailable.

---

## 3. Architectural Requirements

### AR1 — Forward-only event-driven pipeline

The automatic processing path shall be:

`ICamera → SunTracker → Controller → ManualImuCoordinator → Kinematics3RRS → ActuatorManager → ServoDriver`

No stage shall call back into an earlier stage.

Stages may own worker threads where required for blocking I/O or event-driven execution. Threads shall have clear ownership, lifecycle, and no polling or sleep-based timing.

### AR2 — Blocking waits at all thread boundaries

All threads shall block on appropriate primitives until work is available:

| Thread | Mechanism |
|---|---|
| Control | `condition_variable` via queue |
| Actuator | `condition_variable` via queue |
| Event loop | `poll()` |
| Sensors | GPIO edge events |
| SimulatedPublisher | `timerfd` + `poll()` |

No polling loops or busy-waiting are permitted. Execution is driven by blocking I/O and event-triggered wake-ups.

### AR3 — Bounded freshest-data queues

Inter-thread communication shall use bounded queues with latest-wins behaviour:

- frame queue capacity: 2
- command queue capacity: 8

Oldest data is discarded when full.

### AR4 — Graceful optional feature degradation

Optional components shall not break the build:

- libcamera absent → fallback
- OpenCV absent → disable camera backend
- Qt absent → GUI skipped
- IMU failure handled by mode

### AR5 — Camera and backend substitution

Camera backend shall be substitutable via `ICamera` without modifying downstream stages.

### AR6 — Composition root isolation

`SystemFactory` shall act as the primary top-level assembly point for the application.

Where practical, major dependencies shall be injected into `SystemManager`. Internal runtime-owned support components may still be constructed where required for lifecycle control or startup/teardown coordination.

### AR7 — Centralised state control

All state transitions shall be controlled by `SystemManager` and observable.

### AR8 — Manual-mode timing ownership

Manual GUI and potentiometer callbacks may update desired manual state, but only the control thread shall turn that manual state into downstream `Kinematics3RRS` work.

### AR9 — GUI manual stability policy

GUI manual mode shall not apply live IMU correction by default. The operator-selected GUI target remains continuous and stable, while IMU-assisted correction remains available to other modes according to policy.

---

## 4. Non-Functional Requirements

### NFR1 — End-to-end latency

Measured runtime data demonstrates that total processing latency remains within one frame period at 30 Hz under tested conditions.

### NFR2 — Latency distribution

Vision processing is expected to dominate latency, with control and actuation remaining comparatively small.

### NFR3 — Reproducible build

The system shall build reproducibly using declared dependencies and documented steps.

---

## 5. Safety Requirements

### SR1 — Park on start and stop

Servos shall move to a safe park position during startup and shutdown.

### SR2 — Safe shutdown

Shutdown shall be safe from all states and complete all cleanup steps.

### SR3 — Kinematics fault handling

Invalid kinematics shall prevent actuator output and trigger FAULT.

### SR4 — Output safety enforcement

All actuator outputs shall be clamped and validated before reaching hardware.

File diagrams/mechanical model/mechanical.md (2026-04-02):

# 3RRS Mechanical Model | 3RRS 机械结构模型

[English](#english) | [中文](#中文)

---

## English

SolidWorks mechanical structure models for the Solar Stewart Tracker.

### File Formats

- `.SLDPRT` - SolidWorks part files
- `.SLDASM` - SolidWorks assembly files

### Main Components

#### Motion Platform System
- **The motion platform above.SLDPRT** - Upper motion platform
- **The static platform below.SLDPRT** - Lower static platform

#### Servo System
- **3230 Servo Motor.SLDPRT** - 3230 servo motor
- **Dual-axis servo.SLDASM** - Dual-axis servo assembly
- **Double-axis narrow U bracket.SLDPRT** - Dual-axis narrow U bracket
- **Double-axis wide U bracket.SLDPRT** - Dual-axis wide U bracket

#### Linkage Mechanism
- **L1 arm.SLDPRT** - L1 linkage arm
- **L2 arm.SLDPRT** - L2 linkage arm
- **ball head.SLDPRT** - Ball joint head
- **ball head neck.SLDPRT** - Ball joint neck

#### Steering Components
- **Real-axis steering wheel.SLDPRT** - Real-axis steering wheel
- **Imaginary axis steering wheel.SLDPRT** - Imaginary-axis steering wheel

#### Other Components
- **Raspberry Pi box sketch version.SLDPRT** - Raspberry Pi enclosure (sketch version)
- **sc-16-yp.SLDPRT** - SC-16-YP component
- **I M6.SLDPRT** - M6 fastener
- **di.SLDASM** - Main assembly

---

## 中文

太阳能 Stewart 追踪器的 SolidWorks 机械结构模型。

### 文件格式

- `.SLDPRT` - SolidWorks 零件文件
- `.SLDASM` - SolidWorks 装配体文件

### 主要组件

#### 运动平台系统
- **The motion platform above.SLDPRT** - 上层运动平台
- **The static platform below.SLDPRT** - 下层静态平台

#### 伺服系统
- **3230 Servo Motor.SLDPRT** - 3230 伺服电机
- **Dual-axis servo.SLDASM** - 双轴伺服装配体
- **Double-axis narrow U bracket.SLDPRT** - 双轴窄 U 型支架
- **Double-axis wide U bracket.SLDPRT** - 双轴宽 U 型支架

#### 连杆机构
- **L1 arm.SLDPRT** - L1 连杆臂
- **L2 arm.SLDPRT** - L2 连杆臂
- **ball head.SLDPRT** - 球头
- **ball head neck.SLDPRT** - 球头颈部

#### 转向组件
- **Real-axis steering wheel.SLDPRT** - 实轴转向轮
- **Imaginary axis steering wheel.SLDPRT** - 虚轴转向轮

#### 其他组件
- **Raspberry Pi box sketch version.SLDPRT** - 树莓派外壳草图版本
- **sc-16-yp.SLDPRT** - SC-16-YP 组件
- **I M6.SLDPRT** - M6 螺栓
- **di.SLDASM** - 主装配体

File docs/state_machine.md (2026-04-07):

# System State Machine

This document defines the runtime behaviour of the system as a state machine. It describes the implemented execution flow, including all states, transitions, and operational behaviour.

---

## 1. States

| State | Meaning | Outputs |
|---|---|---|
| IDLE | System not running | No motion |
| STARTUP | Initialisation in progress | Startup sequence in progress |
| NEUTRAL | Transitional safe positioning state | Configured startup park applied |
| SEARCHING | Target not confidently detected | Continuous automatic processing with safe behaviour |
| TRACKING | Target detected with sufficient confidence | Normal closed-loop automatic updates |
| MANUAL | User controls setpoint | Manual target is applied continuously through the control thread |
| STOPPING | Shutdown in progress | Controlled stop sequence |
| FAULT | Failure state | Outputs stopped or held safe |

---

## 2. Transition Rules

| From | To | Trigger |
|---|---|---|
| IDLE | STARTUP | `start()` called |
| STARTUP | FAULT | camera null, driver start failure, manual backend failure, or camera start failure |
| STARTUP | NEUTRAL | successful initialisation |
| NEUTRAL | SEARCHING | startup park applied and `startup_mode == Auto` |
| NEUTRAL | MANUAL | startup park applied and `startup_mode == Manual` |
| SEARCHING | TRACKING | confidence ≥ threshold |
| TRACKING | SEARCHING | confidence < threshold |
| SEARCHING | MANUAL | `enterManual()` |
| TRACKING | MANUAL | `enterManual()` |
| NEUTRAL | MANUAL | `enterManual()` |
| MANUAL | SEARCHING | `exitManual()` |
| SEARCHING | STOPPING | `stop()` called |
| TRACKING | STOPPING | `stop()` called |
| MANUAL | STOPPING | `stop()` called |
| NEUTRAL | STOPPING | `stop()` called |
| STARTUP | STOPPING | `stop()` during startup |
| FAULT | STOPPING | `stop()` called |
| STOPPING | IDLE | shutdown complete |
| ANY ACTIVE STATE | FAULT | critical runtime failure |

---

## 3. State Descriptions

### IDLE

The system is inactive.

- camera is not running
- worker threads are not active
- no actuator commands are produced

### STARTUP

Initialisation phase.

- system marked as running
- camera null check performed
- actuator driver started
- queues reset
- worker threads started
- backend coordinator started
- camera streaming started
- failures lead to FAULT

### NEUTRAL

Short transitional state.

- startup park is applied using predefined actuator values
- transitions to SEARCHING (default) or MANUAL (if `startup_mode == Manual`)

### SEARCHING

System is active but target confidence is low.

- frames are processed continuously
- full automatic pipeline remains active
- motion remains bounded
- transitions to TRACKING when confidence increases

### TRACKING

System operates in closed-loop tracking mode.

- each frame triggers full automatic processing path
- controller, correction, kinematics, and actuator stages are active
- continuous actuator updates
- transitions back to SEARCHING if confidence drops

### MANUAL

User-controlled mode.

- activated via `enterManual()` or by `startup_mode == Manual`
- automatic controller updates are disabled
- the control thread handles only the automatic pipeline — it is **not involved** in manual mode dispatch

**Pot-driven manual (`ManualCommandSource::Pot`):**
- ADS1115 ALERT/RDY GPIO edge fires → `onManualPotSample_()` callback in the ADS1115 thread
- setpoint built via `ManualImuCoordinator` and dispatched **directly** to `Kinematics3RRS`
- timing is driven by the ADS1115 conversion rate — independent of camera frames

**GUI-driven manual (`ManualCommandSource::Gui`):**
- `setManualSetpoint()` → `GuiManualDispatcher::setSetpoint()` → push to bounded queue
- `GuiManualDispatcher` worker thread wakes **immediately** and dispatches directly to `Kinematics3RRS`
- timing is driven by operator input rate — independent of camera frames

Both paths use the same downstream `Kinematics3RRS → ActuatorManager → ServoDriver` pipeline.

IMU correction is applied via `ManualImuCoordinator::applyImuCorrection()` in both paths.

### STOPPING

Shutdown sequence.

- system marked as not running
- camera stopped
- backend coordinator stopped
- frame and command queues stopped
- processing threads joined
- neutral command applied
- driver stopped
- transitions to IDLE

### FAULT

Failure state.

- triggered by null camera, driver failure, backend failure, camera start failure, or invalid kinematics result
- actuator commands are halted or suppressed
- system requires explicit stop to recover

---

## 4. Runtime State Graph

```mermaid
stateDiagram-v2
    [*] --> IDLE

    IDLE --> STARTUP: start()

    STARTUP --> NEUTRAL
    STARTUP --> FAULT

    NEUTRAL --> SEARCHING: startup_mode == Auto
    NEUTRAL --> MANUAL: startup_mode == Manual

    SEARCHING --> TRACKING
    TRACKING --> SEARCHING

    SEARCHING --> MANUAL
    TRACKING --> MANUAL
    NEUTRAL --> MANUAL

    MANUAL --> SEARCHING

    SEARCHING --> FAULT
    TRACKING --> FAULT
    MANUAL --> FAULT
    NEUTRAL --> FAULT

    STARTUP --> STOPPING
    NEUTRAL --> STOPPING
    SEARCHING --> STOPPING
    TRACKING --> STOPPING
    MANUAL --> STOPPING
    FAULT --> STOPPING

    STOPPING --> IDLE
```

---

## 5. Startup and Shutdown Flow

```mermaid
flowchart TD
    A["start()"] --> B["set STARTUP"]
    B --> C{"camera null?"}
    C -- yes --> F1["set FAULT"]

    C -- no --> D{"driver start ok?"}
    D -- no --> F2["set FAULT"]

    D -- yes --> E["reset queues / reset manual state"]
    E --> G["start worker threads + GuiManualDispatcher"]

    G --> H{"backends start ok?"}
    H -- fail --> F3["stop and set FAULT"]

    H -- ok --> I{"camera start ok?"}
    I -- no --> F4["stop and set FAULT"]

    I -- yes --> J["set NEUTRAL"]
    J --> K["apply startup park"]

    K --> L{"startup_mode?"}
    L -- Manual --> M["set MANUAL"]
    L -- Auto --> N["set SEARCHING"]

    O["stop()"] --> P["set STOPPING"]
    P --> Q["camera stop"]
    Q --> R["backends stop"]
    R --> R2["stop GuiManualDispatcher"]
    R2 --> S["stop queues and join threads"]
    S --> T["apply neutral command"]
    T --> U["driver stop"]
    U --> W["set IDLE"]
```

---

## 6. Automatic vs Manual Processing

```mermaid
---
config:
  layout: dagre
---
flowchart TB
 subgraph COL1["Automatic path — control thread"]
    direction TB
        A1["Frame event"]
        A2["frame_q_.push_latest"]
        A3["control thread
wait_pop"]
        A4{"state?"}
        A5["SunTracker.onFrame"]
        A6["Controller.onEstimate"]
        A7["applyImuCorrection"]
        AO(["setpoint"])
        AX["drain — no processing"]
  end
 subgraph COL2["Pot manual path — ADS1115 callback thread"]
    direction TB
        B1["ADS1115 ALERT/RDY
GPIO edge"]
        B2["onManualPotSample_"]
        B3{"state==MANUAL
source==Pot?"}
        B4["buildManualSetpointFromPot"]
        B5["applyImuCorrection"]
        BO(["setpoint"])
        BX["discard"]
  end
 subgraph COL3["GUI manual path — GuiManualDispatcher thread"]
    direction TB
        C1["setManualSetpoint called"]
        C2["GuiManualDispatcher
.setSetpoint"]
        C3["push_latest to
bounded queue"]
        C4["worker thread
wakes immediately"]
        C5{"state==MANUAL
source==Gui?"}
        C6["buildManualSetpointFromGui"]
        C7["applyImuCorrection"]
        CO(["setpoint"])
        CX["discard"]
  end
 subgraph ACT["Actuator path — actuator thread"]
    direction TB
        J["cmd_q_.push_latest"]
        K["actuator thread
wait_pop"]
        L["ActuatorManager.onCommand"]
        M["ServoDriver.apply"]
  end
    A1 --> A2
    A2 --> A3
    A3 --> A4
    A4 -- SEARCHING
TRACKING --> A5
    A5 --> A6
    A6 --> A7
    A7 --> AO
    A4 -- MANUAL
FAULT --> AX
    B1 --> B2
    B2 --> B3
    B3 -- yes --> B4
    B4 --> B5
    B5 --> BO
    B3 -- no --> BX
    C1 --> C2
    C2 --> C3
    C3 --> C4
    C4 --> C5
    C5 -- yes --> C6
    C6 --> C7
    C7 --> CO
    C5 -- no --> CX
    AO --> KIN["⚙️  Kinematics3RRS.onSetpoint"]
    BO --> KIN
    CO --> KIN
    J --> K
    K --> L
    L --> M
    KIN --> J

     KIN:::shared
    classDef path fill:#f0f4ff,stroke:#6677aa,stroke-width:1.5px
    classDef shared fill:#fff8e1,stroke:#e6a800,stroke-width:2px
    classDef actuator fill:#f0fff4,stroke:#44aa66,stroke-width:1.5px
    classDef decision fill:#fff,stroke:#333,stroke-width:1.5px
    classDef discard fill:#fff0f0,stroke:#cc6666,stroke-width:1px
```

---

## 7. Implementation Notes

- automatic processing runs only in SEARCHING and TRACKING
- the control thread handles only the automatic path — it is not involved in manual dispatch
- pot manual commands are event-driven from the ADS1115 ALERT/RDY GPIO edge
- GUI manual commands are event-driven from the `GuiManualDispatcher` worker thread
- both manual paths dispatch directly to `Kinematics3RRS` without camera-frame dependency
- GUI manual mode does not use Qt timers as a control timing source
- invalid kinematic results prevent actuation and trigger FAULT
- state transitions are explicit and centrally controlled in `SystemManager`
- `BackendCoordinator` starts and stops ADS1115 and IMU backends during STARTUP and STOPPING

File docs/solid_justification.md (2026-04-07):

# SOLID Justification

This document describes the class structure of the solar-tracking system and explains how the main class boundaries support realtime behaviour, hardware isolation, testability, and maintenance.

The core runtime pipeline is:

**ICamera → SunTracker → Controller → ManualImuCoordinator → Kinematics3RRS → ActuatorManager → ServoDriver**

`SystemManager` orchestrates that pipeline at runtime. `BackendCoordinator` owns optional hardware backend lifecycle. `GuiManualDispatcher` provides the dedicated event-driven thread for GUI manual mode. `SystemFactory` assembles the runtime graph. `LinuxEventLoop` and the Qt GUI provide application-level control around the processing core.

The system is intentionally structured as a staged pipeline rather than a single tracker class. That separation keeps acquisition, estimation, control, policy coordination, mechanism mapping, safety conditioning, hardware output, and application control distinct. For this system, that improves traceability, simplifies testing, and reduces the risk of mixing timing-sensitive logic with platform-specific code.

---

## Design context

The class structure is shaped by four practical requirements.

First, hardware-facing code must remain isolated from pure logic. Camera backends, I2C access, GPIO-backed manual input, IMU publishing, and PWM output are platform-specific concerns. Vision, control, mapping, and kinematics should not depend directly on those details.

Second, the runtime must preserve an event-driven flow. Sensor and backend events enter the pipeline, are transformed by dedicated stages, and progress toward output through typed interfaces. Clear stage boundaries make that flow explicit.

Third, the system must support development and testing without requiring the full physical platform at all times. Narrow interfaces and focused classes allow software-only tests, simulated inputs, and hardware-smoke checks to coexist.

Fourth, the runtime must remain maintainable as policies, backends, and hardware details change. Each class therefore has a narrow responsibility and an explicit role in the overall data path.

---

## `ICamera`

### Purpose

`ICamera` defines the contract for frame-producing backends.

The rest of the runtime does not need to know whether frames come from a Raspberry Pi camera backend or a software simulator. It only needs a typed frame source with a callback registration mechanism.

### SOLID role

**Single Responsibility Principle**

`ICamera` defines one architectural contract: frame delivery. It does not acquire frames itself, perform tracking, or manage control behaviour.

**Interface Segregation Principle**

The interface remains narrow. Camera consumers depend only on frame-source operations and do not need backend-specific configuration or display logic.

**Dependency Inversion Principle**

Higher-level runtime code depends on `ICamera`, not on concrete camera implementations. That keeps backend choice separate from pipeline logic.

### Boundary value

This boundary prevents camera backend details from leaking into orchestration, vision, or control code. It also allows different frame sources to use the same downstream processing path.

---

## `LibcameraPublisher`

### Purpose

`LibcameraPublisher` provides the Raspberry Pi camera backend behind the `ICamera` contract.

Its job is to acquire frames from the real camera path and publish them into the runtime pipeline. It does not participate in tracking, control, or actuation policy.

### SOLID role

**Single Responsibility Principle**

Its responsibility is camera acquisition for the libcamera path.

**Liskov Substitution Principle**

It can be used anywhere an `ICamera` is required.

**Dependency Inversion Principle**

The rest of the system remains dependent on the camera abstraction while this class absorbs the backend-specific API.

### Boundary value

This class isolates libcamera lifecycle and integration details from the rest of the runtime. That keeps the pipeline independent of camera-stack implementation details.

---

## `SimulatedPublisher`

### Purpose

`SimulatedPublisher` provides a software-only frame source through the same `ICamera` contract.

It supports development, testing, and runtime execution when the real camera path is unavailable or unnecessary.

### SOLID role

**Single Responsibility Principle**

Its responsibility is synthetic frame generation and publication.

**Liskov Substitution Principle**

It can replace `LibcameraPublisher` anywhere `ICamera` is consumed.

**Open/Closed Principle**

Additional camera implementations can be introduced without redesigning the consumers of `ICamera`.

### Boundary value

Simulation remains a first-class backend rather than an internal conditional path buried in runtime orchestration.

---

## `SunTracker`

### Purpose

`SunTracker` is the vision stage. It converts a `FrameEvent` into a `SunEstimate`.

It validates frame layout assumptions, interprets image data, detects the target, and emits a typed estimate for downstream control.

### SOLID role

**Single Responsibility Principle**

Its reason to change is the target-detection method.

**Open/Closed Principle**

Tracking internals can evolve while preserving the `SunEstimate` contract used downstream.

**Encapsulation**

Frame validation and image-processing details remain contained within the tracker.

### Boundary value

This class separates image interpretation from runtime orchestration, control, and hardware output. That keeps vision faults and control faults easier to localise.

---

## `Controller`

### Purpose

`Controller` converts a tracking estimate into a platform setpoint.

It handles confidence gating, deadband behaviour, and command generation in platform coordinates.

### SOLID role

**Single Responsibility Principle**

Its reason to change is the control-law policy from estimate space to platform-command space.

**Open/Closed Principle**

Gains, deadband policy, saturation, and confidence handling can change without restructuring downstream stages.

**Dependency Inversion Principle**

The controller depends on typed estimate data rather than on camera backends or hardware output details.

### Boundary value

This stage separates control policy from both vision and mechanism mapping. That preserves a clear distinction between “what the platform should do” and “how the mechanism achieves it”.

---

## `ManualImuCoordinator`

### Purpose

`ManualImuCoordinator` owns command-policy coordination for manual control and IMU-based correction.

Its responsibilities include:

- mapping manual potentiometer samples to platform setpoints
- selecting whether potentiometer or GUI input owns manual commands
- storing the latest IMU sample and tilt estimate
- applying optional IMU correction to controller setpoints

### SOLID role

**Single Responsibility Principle**

Its responsibility is command-policy coordination for manual ownership and tilt feedback.

**Open/Closed Principle**

Manual-input ownership rules and IMU-correction rules can evolve within this policy layer without restructuring runtime orchestration.

**Dependency Inversion Principle**

It depends on dedicated helpers such as `ManualInputMapper`, `ImuTiltEstimator`, and `ImuFeedbackMapper` rather than embedding those algorithms inline.

### Boundary value

This class keeps manual-command policy and IMU-correction policy out of `SystemManager`, reducing orchestration complexity and preserving focused runtime responsibilities.

---

## `ManualInputMapper`

### Purpose

`ManualInputMapper` converts manual input values into platform commands.

This is pure mapping logic and does not belong in the ADC/input backend or in runtime orchestration.

### SOLID role

**Single Responsibility Principle**

Its reason to change is the mapping from manual input values to commanded motion.

**Dependency Inversion Principle**

Higher-level policy code depends on a dedicated mapper rather than repeating scaling logic inline.

### Boundary value

This class keeps command semantics separate from hardware acquisition details.

---

## `ImuTiltEstimator`

### Purpose

`ImuTiltEstimator` converts reduced IMU acceleration data into a tilt estimate.

It is a pure estimation component.

### SOLID role

**Single Responsibility Principle**

Its reason to change is the tilt-estimation method.

**Dependency Inversion Principle**

Policy code depends on a dedicated estimator rather than embedding estimation logic into runtime control code.

### Boundary value

This class separates sensor transport from signal interpretation.

---

## `ImuFeedbackMapper`

### Purpose

`ImuFeedbackMapper` converts measured tilt into a bounded correction term.

It is a control-support policy component.

### SOLID role

**Single Responsibility Principle**

Its reason to change is the correction policy: gain, deadband, and output limits.

**Open/Closed Principle**

Correction behaviour can be refined without redesigning orchestration, backend startup, or hardware output code.

### Boundary value

This class makes tilt-correction policy explicit and testable.

---

## `Kinematics3RRS`

### Purpose

`Kinematics3RRS` transforms a platform setpoint into actuator commands for the 3-RRS mechanism.

It is mechanism-specific mapping, separate from both control-law policy and hardware output.

### SOLID role

**Single Responsibility Principle**

Its responsibility is mechanism mapping, including geometry, calibration, and inverse-kinematics behaviour.

**Open/Closed Principle**

Mechanism details can change here while preserving the upstream platform-setpoint contract.

**Encapsulation**

Geometry and calibration parameters remain contained in a dedicated configuration structure.

### Boundary value

This class preserves the physical meaning of the intermediate platform setpoint and keeps the mechanism model explicit rather than implicit.

---

## `ActuatorManager`

### Purpose

`ActuatorManager` is the actuator safety-conditioning stage.

It clamps actuator outputs and applies slew-rate limiting before commands reach the servo driver.

### SOLID role

**Single Responsibility Principle**

Its responsibility is actuator-command conditioning.

**Open/Closed Principle**

Safety policy can change without redesigning low-level hardware access.

**Dependency Inversion Principle**

Downstream hardware code receives already-conditioned commands rather than raw control outputs.

### Boundary value

This class keeps safety policy separate from both mechanism mapping and final hardware output.

---

## `ServoDriver`

### Purpose

`ServoDriver` is the final servo-output stage.

Its responsibilities are:

- degree-to-pulse conversion
- PCA9685 access policy
- application of already-conditioned commands
- startup and stop parking behaviour

It does not own control policy, kinematics, or queueing.

### SOLID role

**Single Responsibility Principle**

Its responsibility is final servo output handling.

**Open/Closed Principle**

Calibration, startup policy, and parking behaviour can change without restructuring upstream control or kinematics code.

**Dependency Inversion Principle**

The rest of the pipeline operates in actuator-command units without depending directly on PWM register access.

### Boundary value

This class keeps electrical and channel-mapping behaviour separate from motion semantics and safety policy.

---

## `PCA9685`

### Purpose

`PCA9685` encapsulates the low-level PWM chip behaviour.

Register-level I2C interaction is isolated here rather than spread through higher-level output code.

### SOLID role

**Single Responsibility Principle**

Its responsibility is PCA9685 chip access.

**Dependency Inversion Principle**

Higher-level output stages use a dedicated chip wrapper rather than embedding low-level register access directly.

### Boundary value

This class prevents low-level bus and register operations from leaking upward into servo policy or control code.

---

## `BackendCoordinator`

### Purpose

`BackendCoordinator` owns the lifecycle of the two optional hardware backends:
the ADS1115 manual potentiometer input and the MPU-6050/ICM-20600 IMU.

This class was extracted from `SystemManager` to give backend resource ownership
an explicit, single-responsibility boundary. `SystemManager` no longer needs to
know about I2C device construction, backend start/stop sequencing, or the
`ImuCallbackForwarder` adaptor — those details are encapsulated here.

### SOLID role

**Single Responsibility Principle** — Responsibility is hardware backend lifecycle:
I2C device construction, start/stop sequencing, and sample delivery via callbacks.

**Interface Segregation Principle** — `SystemManager` depends only on
`BackendCoordinator::start()` and `stop()`. It has no visibility into which
backends are active or how their callbacks are routed.

### Boundary value

Separating backend lifecycle from pipeline orchestration means `SystemManager`
can be tested and reasoned about independently of hardware availability.

---

## `GuiManualDispatcher`

### Purpose

`GuiManualDispatcher` provides the dedicated event-driven thread for GUI manual
mode. When `setSetpoint()` is called (from the Qt UI thread), the setpoint is
pushed into a bounded freshest-data queue. The dispatcher's worker thread blocks
on that queue and wakes immediately, building a platform setpoint via
`ManualImuCoordinator` and dispatching directly to `Kinematics3RRS`.

This class was introduced to remove the asymmetry where GUI manual mode depended
on camera-frame wakeups while potentiometer manual mode was directly event-driven.
Both manual paths now have structurally identical, independently-timed event paths.

### SOLID role

**Single Responsibility Principle** — Responsibility is GUI setpoint delivery:
one queue, one thread, one dispatch path.

**Open/Closed Principle** — The dispatcher works with any `ManualImuCoordinator`
and any `Kinematics3RRS` instance without modification.

**Interface Segregation Principle** — `SystemManager` depends on only
`setSetpoint()`, `start()`, and `stop()`. The internal queue and thread are
fully encapsulated.

### Boundary value

`setManualSetpoint()` on `SystemManager` is now a one-line forwarding call.
The timing, queuing, and dispatch logic are entirely contained in this class.

---

## `SystemManager`

### Purpose

`SystemManager` is a thin runtime orchestrator. Its responsibilities are:
- composing pipeline stages
- owning two worker threads and two inter-thread queues
- managing the runtime state machine (IDLE / STARTUP / SEARCHING / TRACKING /
  MANUAL / FAULT / STOPPING)
- lifecycle management (start / stop)
- observer registration forwarding

Backend lifecycle is delegated to `BackendCoordinator`. GUI manual dispatch is
delegated to `GuiManualDispatcher`. Manual/IMU policy is delegated to
`ManualImuCoordinator`. `SystemManager` itself is approximately 380 lines.

### SOLID role

**Single Responsibility Principle** — Responsibility is pipeline orchestration
and runtime state coordination. It does not implement vision, control law,
kinematics, safety shaping, hardware access, or GUI manual timing.

**Dependency Inversion Principle** — Depends on `ICamera` (not a concrete
backend), `ManualImuCoordinator` (not manual hardware), and
`GuiManualDispatcher` (not Qt directly).

**Encapsulation** — Exposes explicit observer registration and control methods.
Internal queue and thread management is private.

### Honest assessment

`controlLoop_()` is now 10 lines with a single responsibility: drain camera
frames and forward them to the automatic processing path. The manual branches
have been fully removed. The class is substantially smaller than its previous
form and its responsibilities are clearly bounded.

---

## `ThreadSafeQueue`

### Purpose

`ThreadSafeQueue` provides blocking handoff between producer and consumer stages.

Its architectural value is not only storage. It also defines blocking wait behaviour and bounded freshest-data queue policy for the runtime pipeline.

### SOLID role

**Single Responsibility Principle**

Its responsibility is inter-thread queue handoff.

**Open/Closed Principle**

Queue policy remains encapsulated in one place instead of being reimplemented ad hoc across the runtime.

**Safe data management**

It uses STL-managed storage, explicit stop/reset behaviour, blocking waits, and bounded latest-only insertion.

### Boundary value

This class provides deterministic handoff points between worker threads and avoids shared-state polling designs.

---

## `LinuxEventLoop`

### Purpose

`LinuxEventLoop` isolates headless application-shell events from the realtime processing pipeline.

It keeps process-level input handling and shutdown behaviour outside the tracking stages.

### SOLID role

**Single Responsibility Principle**

Its responsibility is the headless application event loop.

### Boundary value

This class keeps shell-level process control separate from the tracking runtime.

---

## `SystemFactory`

### Purpose

`SystemFactory` is the composition root.

It selects and constructs the runtime graph and keeps assembly logic out of `main()`.

### SOLID role

**Single Responsibility Principle**

Its responsibility is runtime assembly.

**Dependency Inversion Principle**

It centralises concrete-type selection while allowing the running system to depend on narrower interfaces and stage contracts.

### Boundary value

This class keeps backend selection and object assembly separate from runtime execution.

---

## Callback structure

Callbacks are the primary inter-stage event mechanism in the processing pipeline.

That choice fits this runtime because sensor and backend events arrive asynchronously and must be pushed forward through the staged pipeline. Callback boundaries make event timing explicit, keep freshness aligned with stage handoff, and avoid pull-style designs in which downstream code repeatedly queries upstream state.

In this system, callback-based stage interfaces support:

- explicit event timing
- stage-local ownership of processing
- reduced coupling between pipeline stages
- direct integration with blocking/event-driven input paths
- clearer test boundaries between producers and consumers

---

## Output-side command flow

The output side follows a staged command progression.

- `Controller` produces platform setpoints
- `Kinematics3RRS` produces actuator commands
- `ActuatorManager` conditions those commands
- `ServoDriver` applies final hardware-oriented output behaviour

Each stage hands forward a more concrete representation of the command while preserving clear ownership of policy, mechanism mapping, safety conditioning, and hardware output.

---

## Architectural summary

The class structure separates the runtime into distinct layers:

- acquisition boundary
- estimation boundary
- control boundary
- manual/IMU policy boundary
- mechanism-mapping boundary
- safety-conditioning boundary
- final hardware-output boundary
- orchestration boundary
- application-shell boundary

That separation supports hardware isolation, event-driven processing, bounded inter-thread handoff, staged reasoning about faults, and focused testing of individual behaviours.

## Final judgement

The class structure is strongest where it keeps platform-specific code isolated, preserves clear event flow between stages, and separates policy, computation, orchestration, and hardware output into dedicated boundaries.

The key architectural decisions are:

- `ICamera` as the frame-source abstraction
- backend isolation in `LibcameraPublisher` and `SimulatedPublisher`
- dedicated logic stages in `SunTracker`, `Controller`, `ManualInputMapper`, `ImuTiltEstimator`, and `ImuFeedbackMapper`
- policy isolation in `ManualImuCoordinator`
- mechanism isolation in `Kinematics3RRS`
- safety conditioning in `ActuatorManager`
- final hardware mapping isolation in `ServoDriver` and `PCA9685`
- orchestration in `SystemManager`
- runtime assembly in `SystemFactory`

Together, these boundaries support a maintainable staged runtime rather than a tightly coupled monolithic tracker implementation.

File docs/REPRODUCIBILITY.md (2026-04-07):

# Reproducibility

## Purpose

This document explains how to reproduce the  repository  from source using the files: `CMakeLists.txt`, `.github/workflows/`, `scripts/`, `.gitmodules`, `external/`, `src/`, and `docs/`.

---

## 0. Reference Platform

All latency measurements and hardware-smoke tests were captured on the following exact platform:

| Parameter | Value |
|---|---|
| Hardware | Raspberry Pi 5 Model B, 4 GB RAM |
| CPU | Broadcom BCM2712, Cortex-A76, 4-core, 2.4 GHz |
| Operating system | Raspberry Pi OS Bookworm (Debian 12), 64-bit (aarch64) |
| Kernel | Linux 6.6.51+rpt-rpi-2712 (aarch64) |
| Compiler | GCC 12.2.0 (aarch64-linux-gnu) |
| libgpiod | 2.2.2 (built from source) |
| OpenCV | 4.10.0 (`libopencv-dev` via apt) |
| libcamera | 0.3.2 (`libcamera-dev` via apt) |
| Qt | Qt 5.15.8 (`qtbase5-dev libqt5charts5-dev` via apt) |

---

## 1. Source of Truth

The reproducible source of truth in this repository is:

| Path | Role |
|---|---|
| `src/` | Application and library source code |
| `CMakeLists.txt` | Top-level build definition |
| `.gitmodules` | External submodule declarations |
| `external/` | External support code checked out via submodules |
| `scripts/` | Build, test, documentation, latency, and packaging helper scripts |
| `.github/workflows/` | CI, documentation, hardware-smoke, and release automation |
| `artefacts/latency.csv` | Captured software latency measurements |
| `Doxyfile` | API documentation configuration |

---

## 2. External Dependencies

### Git Submodules

Two external repositories are declared in `.gitmodules`:

| Submodule | Path | URL |
|---|---|---|
| `libgpiod_event_demo` | `external/libgpiod_event_demo` | `https://github.com/berndporr/libgpiod_event_demo` |
| `libcamera2opencv` | `external/libcamera2opencv` | `https://github.com/berndporr/libcamera2opencv` |

These should be fetched with:

```bash
git submodule update --init --recursive
```

### System Packages

The Ubuntu CI workflow installs these packages directly:

```bash
sudo apt-get update
sudo apt-get install -y \
  autoconf \
  autoconf-archive \
  automake \
  cmake \
  g++ \
  libjsoncpp-dev \
  libtool \
  make \
  ninja-build \
  pkg-config \
  wget \
  xz-utils
```

The CI workflow then builds and installs **libgpiod v2.2.2** from source so that the C++ bindings are available.

For local Linux reproduction, the following additional packages may be needed depending on which optional features are enabled:

- `libopencv-dev` for OpenCV-dependent paths
- `libcamera-dev` for the Raspberry Pi libcamera backend
- `qtbase5-dev` for the Qt GUI target
- `graphviz` and `doxygen` for API documentation generation
- `i2c-tools` for Raspberry Pi hardware-smoke workflows

---

## 3. CMake Build Options

The top-level build defines the following options:

| Option | Default | Effect |
|---|---|---|
| `SOLAR_ENABLE_TESTS` | `ON` | Build and register test targets |
| `SOLAR_ENABLE_HW_TESTS` | `OFF` | Register real hardware smoke tests |
| `SOLAR_ENABLE_QT` | `ON` | Build the Qt GUI target if Qt5 is available |
| `SOLAR_TRY_LIBCAMERA` | `ON` | Probe for the libcamera backend |
| `SOLAR_TRY_OPENCV` | `ON` | Probe for OpenCV support |
| `SOLAR_ENABLE_COVERAGE` | `OFF` | Enable coverage compile/link flags where supported |

Feature probing behaves as follows:

- if OpenCV is not found, OpenCV-dependent functionality is disabled
- if libcamera is found but OpenCV is not found, the libcamera backend is disabled
- if Qt5 is not found, the Qt GUI target is skipped
- if `external/libgpiod_event_demo` is missing, GPIO demo support is disabled

---

## 4. Clean Reproduction Procedure

```bash
# Step 1 — clone
git clone <repo-url>
cd Solar-Stewart-Tracker

# Step 2 — initialise submodules
git submodule update --init --recursive

# Step 3 — install build dependencies
sudo apt-get update
sudo apt-get install -y \
  cmake \
  ninja-build \
  g++ \
  pkg-config \
  libjsoncpp-dev

# Optional packages for optional features
# sudo apt-get install -y libopencv-dev libcamera-dev qtbase5-dev doxygen graphviz i2c-tools

# Step 4 — configure
cmake -S . -B build -G Ninja -DCMAKE_BUILD_TYPE=Release

# Step 5 — build
cmake --build build --parallel

# Step 6 — run software tests
ctest --test-dir build --output-on-failure --verbose

# Step 7 — run the headless application
./build/solar_tracker

# Step 8 — run the Qt GUI if Qt was found at configure time
./build/solar_tracker_qt
```

---

## 5. Helper Scripts in `scripts/`

The repository  contains these helper scripts:

| Script | Purpose |
|---|---|
| `scripts/build_core.sh` | Configure and build the main software targets |
| `scripts/build_docs.sh` | Generate Doxygen documentation |
| `scripts/build_pi_debug.sh` | Configure a Pi-oriented debug build |
| `scripts/test_core.sh` | Run the software test suite |
| `scripts/test_pi_hw.sh` | Run hardware-labelled smoke tests on Raspberry Pi |
| `scripts/run_latency.sh` | Run the application with latency CSV export enabled |
| `scripts/package_release.sh` | Package a release zip |

---

## 6. CI Automation

Four workflows are defined in `.github/workflows/`:

| Workflow | Trigger | Runner |
|---|---|---|
| `ci.yml` | push to `main`, pull request to `main`, manual dispatch | `ubuntu-latest` |
| `doxygen.yml` | push to `main` or `master`, manual dispatch | `ubuntu-latest` |
| `release.yml` | release created, manual dispatch | `ubuntu-latest` |
| `pi-hardware-tests.yml` | manual dispatch | self-hosted `linux/arm64` |

### Standard CI (`ci.yml`)

The standard CI workflow performs the following steps:

1. checks out the repository with submodules
2. installs build dependencies
3. builds and installs `libgpiod` v2 with C++ bindings from source
4. configures the project with CMake and Ninja
5. builds the repository
6. runs `ctest --test-dir build --output-on-failure --verbose`

### Doxygen workflow (`doxygen.yml`)

The documentation workflow:

1. checks out the repository with submodules
2. installs `doxygen` and `graphviz`
3. runs `bash ./scripts/build_docs.sh`
4. uploads `docs/html` as the Pages artifact
5. deploys to GitHub Pages

### Release workflow (`release.yml`)

The release workflow:

1. checks out the repository with submodules
2. installs build dependencies
3. runs `bash ./scripts/build_core.sh build`
4. runs `bash ./scripts/package_release.sh build solar-stewart-tracker-release.zip`
5. uploads the packaged release artifact

### Raspberry Pi hardware-smoke workflow (`pi-hardware-tests.yml`)

The Pi workflow:

1. checks out the repository with submodules
2. installs Pi-side dependencies including `i2c-tools`
3. configures a debug build with `SOLAR_ENABLE_HW_TESTS=ON`
4. builds curated hardware-smoke targets
5. runs `bash ./scripts/test_pi_hw.sh "${BUILD_DIR}"`
6. uploads CTest logs and cache files as artifacts

---

## 7. Hardware Reproduction

The repository assumes a Raspberry Pi Linux target with the following hardware path available for full reproduction:

- Raspberry Pi running Linux
- I2C bus exposed as `/dev/i2c-1`
- PCA9685 PWM controller
- ADS1115 ADC for manual input sampling
- MPU6050 IMU
- GPIO event support through `libgpiod`
- Raspberry Pi camera path compatible with libcamera if the libcamera backend is used

### Hardware Test Environment Variables

The hardware-smoke script uses these environment variables:

| Variable | Default | Meaning |
|---|---|---|
| `SOLAR_RUN_CAMERA_HW_TESTS` | `1` | Enable camera hardware checks |
| `SOLAR_RUN_I2C_HW_TESTS` | `1` | Enable I2C hardware checks |
| `SOLAR_I2C_DEV` | `/dev/i2c-1` | I2C device path |

### Enabling Hardware Tests

```bash
cmake -S . -B build \
  -G Ninja \
  -DCMAKE_BUILD_TYPE=Debug \
  -DSOLAR_ENABLE_TESTS=ON \
  -DSOLAR_ENABLE_HW_TESTS=ON \
  -DSOLAR_ENABLE_QT=OFF \
  -DSOLAR_TRY_LIBCAMERA=OFF \
  -DSOLAR_TRY_OPENCV=OFF

cmake --build build --parallel
./scripts/test_pi_hw.sh build
```

---

## 8. Latency Data Reproduction

The repository includes `artefacts/latency.csv` as captured software latency evidence.

The same output path can be regenerated with:

```bash
./scripts/run_latency.sh build artefacts/latency.csv solar_tracker
```

This script sets the `SOLAR_LATENCY_CSV` environment variable before launching the application. At shutdown, the runtime `LatencyMonitor` writes per-frame measurements to the specified CSV path.

---

## 9. Non-Hardware Reproduction

If physical hardware is unavailable:

- the software test suite still runs
- hardware-smoke tests remain disabled by default because `SOLAR_ENABLE_HW_TESTS` defaults to `OFF`
- the application can run through the simulated camera backend path when hardware backends are not available

This allows code-level reproduction of the processing pipeline without requiring the full physical platform.

---

## 10. API Documentation Reproduction

A `Doxyfile` is  at the repository root.

Local generation:

```bash
doxygen Doxyfile
```

The repository also contains `scripts/build_docs.sh`, which is used by the GitHub documentation workflow.

---

## 11. Summary

This repository can be reproduced from source because it contains:

- the top-level build definition
- the declared submodules
- the build, test, latency, documentation, and packaging scripts
- the CI workflows
- the source tree
- the API documentation configuration
- the captured software latency artifact

A software-only reproduction path is available on a normal Linux system, and a fuller Raspberry Pi hardware-smoke path is defined separately for the target platform.

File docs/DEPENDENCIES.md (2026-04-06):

# Dependencies

## Purpose

This document lists all dependencies required to build and run. All hardware defaults are sourced directly from `src/app/AppConfig.cpp` and `src/app/AppConfig.hpp`.

---

## 1. Core Build Requirements

From `CMakeLists.txt`:

| Requirement | Minimum |
|---|---|
| CMake | 3.16 |
| C++ standard | C++17 |
| Compiler flags | `-Wall -Wextra -Wpedantic` (GCC/Clang) |
| Threads | `find_package(Threads REQUIRED)` |
| pkg-config | `find_package(PkgConfig REQUIRED)` |

```bash
sudo apt-get install -y cmake ninja-build g++ pkg-config git
```

---

## 2. Required Runtime Dependency

### libgpiod

Required unconditionally. Used by the ADS1115 manual input and MPU6050 IMU backends for GPIO edge event handling via `libgpiod_event_demo`.

```bash
# libgpiod v2 must be built from source — apt provides v1.x only.
# See docs/build_and_run.md for the full build-from-source instructions.
# The C++ bindings (gpiod.hpp) are only available in v2.
```

---

## 3. Optional Feature Dependencies

All optional features are probed at configure time and degrade gracefully if absent. The build always succeeds.

### Qt5 — GUI target (`solar_tracker_qt`)

Requires **both** `Widgets` and `Charts` components. If either is missing, `solar_tracker_qt` is silently skipped.

```bash
sudo apt-get install -y qtbase5-dev libqt5charts5-dev
```

Controlled by: `-DSOLAR_ENABLE_QT=ON` (default)

### OpenCV — vision processing and libcamera bridge

Required for image frame processing in `SunTracker` and as a prerequisite for the libcamera backend.

```bash
sudo apt-get install -y libopencv-dev
```

Controlled by: `-DSOLAR_TRY_OPENCV=ON` (default)

### libcamera — Raspberry Pi camera backend

Enables the `LibcameraPublisher` camera backend. **Requires OpenCV to also be present** — the CMake configuration explicitly checks for both:

```
if(LIBCAMERA_FOUND AND SOLAR_HAVE_OPENCV) → backend enabled
if(LIBCAMERA_FOUND AND NOT SOLAR_HAVE_OPENCV) → backend disabled
```

```bash
sudo apt-get install -y libcamera-dev
```

Controlled by: `-DSOLAR_TRY_LIBCAMERA=ON` (default)

> Installing libcamera without OpenCV will not enable the libcamera backend.

---

## 4. External Repository Dependencies

### Git Submodules

This repository has **two** git submodules in `.gitmodules`:

| Submodule | Path | Role in this repository |
|---|---|---|
| libgpiod_event_demo | `external/libgpiod_event_demo` | GPIO edge-event callback support used by the ADS1115 manual-input and MPU6050 data-ready paths |
| libcamera2opencv | `external/libcamera2opencv` | libcamera-to-OpenCV bridge used only when libcamera and OpenCV support are both enabled |

```bash
git submodule update --init --recursive
```
---

## 5. Linux Kernel Interfaces

The following kernel interfaces are used at runtime:

| Interface | Used by |
|---|---|
| `/dev/i2c-1` | PCA9685, ADS1115, MPU6050 |
| GPIO chip 0 | ADS1115 ALERT/RDY, MPU6050 data-ready |
| `poll()` | `LinuxEventLoop`, `SimulatedPublisher` |
| `signalfd` | `LinuxEventLoop` — SIGINT/SIGQUIT/SIGHUP/SIGTERM shutdown |
| `timerfd` (CLOCK_MONOTONIC) | `LinuxEventLoop` (CLI tick), `SimulatedPublisher` (frame pacing) |
| `eventfd` | `SimulatedPublisher` — clean stop wakeup |

---

## 6. Hardware Dependencies and Default Configuration

All defaults are from `src/app/AppConfig.cpp` (`defaultConfig()`).

### PCA9685 — Servo Driver

| Parameter | Default |
|---|---|
| I2C bus | 1 (`/dev/i2c-1`) |
| I2C address | `0x40` |
| PWM frequency | 50 Hz |
| Pulse range | 500 – 2500 µs |
| Servo range | 0° – 180° |
| Park angle | 41° (all three channels) |
| Park on start | enabled |
| Park on stop | enabled |
| Channel mapping | ch0 → PCA pin 2, ch1 → PCA pin 0, ch2 → PCA pin 1 |

### ADS1115 — Manual Input (Potentiometers)

| Parameter | Default |
|---|---|
| I2C bus | 1 (`/dev/i2c-1`) |
| I2C address | `0x48` |
| GPIO chip | 0 |
| ALERT/RDY GPIO pin | 17 |
| Tilt channel | 0 |
| Pan channel | 1 |
| Full-scale voltage | ±4.096 V |
| Sample rate | 128 Hz |
| Pot supply voltage | 3.3 V |

Manual input is **enabled by default** in `defaultConfig()`.

### MPU6050 — IMU

| Parameter | Default |
|---|---|
| I2C bus | 1 (`/dev/i2c-1`) |
| I2C address | `0x68` |
| GPIO chip | 0 |
| Data-ready GPIO pin | 27 |
| WHO\_AM\_I expected | `0x70` (ICM-20600 variant; standard MPU-6050 returns `0x68`) |
| Startup discard samples | 8 |
| Accel sensitivity | 16384 LSB/g (±2g range) |
| Gyro sensitivity | 131 LSB/°s (±250°/s range) |

IMU is **enabled by default** in `defaultConfig()` in Shadow mode. Qt runtime uses Live mode.

### Camera

| Backend | Condition | Default resolution | Default FPS |
|---|---|---|---|
| `SimulatedPublisher` | Always available | 640 × 480 | 30 |
| `LibcameraPublisher` | Requires libcamera **and** OpenCV | 640 × 480 | 30 |

When built with libcamera support, `defaultConfig()` selects `Libcamera` and sets `ServoDriver::StartupPolicy::RequireHardware`. Without libcamera, it selects `Simulated` and `LogOnly`.

### Stewart Platform Kinematics

| Parameter | Default |
|---|---|
| Base radius | 0.20 m |
| Platform radius | 0.12 m |
| Home height | 0.18 m |
| Horn length | 0.10 m |
| Rod length | 0.18 m |
| Base joint angles | 120°, 240°, 0° |
| Platform joint angles | 120°, 240°, 0° |
| Servo neutral positions | 90°, 90°, 90° |
| Servo directions | −1, −1, −1 |

---

## 7. Hardware Validation

Before running on real hardware, verify I2C and GPIO availability:

```bash
# Verify I2C devices are visible on bus 1
# Expected: PCA9685 at 0x40, ADS1115 at 0x48, MPU6050 at 0x68
i2cdetect -y 1

# List available GPIO chips and lines
gpioinfo
```

---

## 8. CMake Option Reference

| Option | Default | Effect |
|---|---|---|
| `SOLAR_ENABLE_TESTS` | `ON` | Build test targets |
| `SOLAR_ENABLE_HW_TESTS` | `OFF` | Register hardware smoke tests with CTest |
| `SOLAR_ENABLE_QT` | `ON` | Build `solar_tracker_qt` if Qt5 found |
| `SOLAR_TRY_LIBCAMERA` | `ON` | Probe for libcamera (also requires OpenCV) |
| `SOLAR_TRY_OPENCV` | `ON` | Probe for OpenCV |
| `SOLAR_ENABLE_COVERAGE` | `OFF` | Enable `--coverage` compile/link flags |

---

## 9. Full Install Command

```bash
# Required
sudo apt-get install -y cmake ninja-build g++ pkg-config git libgpiod-dev

# Optional — Qt GUI
sudo apt-get install -y qtbase5-dev libqt5charts5-dev

# Optional — vision and libcamera (both needed together)
sudo apt-get install -y libopencv-dev libcamera-dev

# Optional — hardware validation
sudo apt-get install -y i2c-tools
```
---

## 6. ADS1115 Manual Input — Library Decision

Dr Porr's `rpi_ads1115` library (`https://github.com/berndporr/rpi_ads1115`) was evaluated for the manual potentiometer input path. The library uses the correct ALERT/RDY GPIO edge callback architecture and integrates cleanly with `libgpiod_event_demo`.

**Hardware constraint encountered:** The library hardcodes the ADS1115 PGA (Programmable Gain Amplifier) to ±2.048V internally. The potentiometers on the rig are powered from the Raspberry Pi 3.3V rail, producing a wiper voltage of 0–3.3V. With the ±2.048V PGA, any ADC input above approximately 2.047V clips at the full-scale reading — approximately 62% of pot travel produces the same maximum output, leaving 38% of the physical range unusable.

**Engineering decision:** Rather than modifying the submodule source (which would prevent clean upstream updates) or adding hardware voltage scaling (not available at time of implementation), a project-native ADS1115 driver was written: `src/sensors/manual/ADS1115ManualInput.cpp`.

The native driver uses the same ALERT/RDY GPIO edge callback pattern as `libgpiod_event_demo` and configures the PGA to ±4.096V, which covers the full 0–3.3V potentiometer range without clipping.

| Parameter | rpi_ads1115 submodule | Project-native ADS1115ManualInput |
|---|---|---|
| PGA setting | ±2.048V (hardcoded) | ±4.096V (configurable) |
| Full pot range usable | No — clips at 62% | Yes — full 0–3.3V |
| GPIO callback pattern | ALERT/RDY edge | ALERT/RDY edge (identical) |
| Multi-channel support | Single channel per instance | Interleaved tilt + pan channels |

**Future path:** The hardware fix is a 180Ω + 270Ω resistor voltage divider to power the pot VCC from ~1.97V instead of 3.3V. This would allow the `rpi_ads1115` submodule to be used directly without any code modification. This was planned but not implemented due to component availability at time of submission.

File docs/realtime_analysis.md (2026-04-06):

# Realtime Analysis

## Purpose

This document describes the realtime execution model and timing behaviour of the system.

---

## 1. Runtime Model

The system operates as a Linux userspace, event-driven runtime built on:

- poll() on file descriptors for application-level events  
- blocking std::condition_variable waits for inter-thread communication  
- GPIO edge-triggered callbacks for hardware sensor events  
- explicit state machine transitions  

No component introduces polling loops, sleep()-based pacing, or busy-waiting in the processing path.

---

## 2. Application Event Loop — LinuxEventLoop

src/app/LinuxEventLoop.cpp implements the headless runtime lifecycle. It multiplexes event sources using a single poll() call with an infinite timeout (-1).

File descriptors:

- signalfd → SIGINT / SIGQUIT / SIGHUP / SIGTERM → clean shutdown  
- timerfd (CLOCK_MONOTONIC) → configurable tick (default 30 Hz) → CLI servicing  
- stdin (dup’d) → terminal input  

The loop remains blocked in the kernel until an event occurs.

---

## 3. Inter-Thread Queues — ThreadSafeQueue

src/common/ThreadSafeQueue.hpp provides blocking data transfer between worker threads using std::mutex and std::condition_variable with wait_pop().

Two queues are defined in SystemManager:

- frame_q_ → ThreadSafeQueue<FrameEvent> → capacity 2 → push_latest()  
- cmd_q_ → ThreadSafeQueue<ActuatorCommand> → capacity 8 → push_latest()  

The push_latest() policy ensures consumers process the most recent data when under load. Queue sizes remain bounded.

---

## 4. Worker Threads

SystemManager owns two worker threads.

Control thread (controlLoop_):

- blocks on frame_q_.wait_pop()  
- processes frames through SunTracker and Controller in automatic modes  
- builds manual setpoints from stored input state in manual mode  
- performs all command generation  

Actuator thread (actuatorLoop_):

- blocks on cmd_q_.wait_pop()  
- applies ActuatorManager → ServoDriver  
- no alternative actuation path exists  

---

## 5. Sensor Wakeups

Camera:

- SimulatedPublisher uses timerfd + poll() + eventfd  
- LibcameraPublisher delivers frames via callback-based backend  

Manual input:

- ADS1115ManualInput uses ALERT/RDY GPIO edge  
- callback updates stored manual state only  

IMU:

- Mpu6050Publisher uses GPIO data-ready interrupt  
- samples forwarded to coordinator  

---

## 6. Data Flow

Automatic path:

Frame callback  
→ frame_q_.push_latest(...)  
→ control thread wait_pop()  
→ SunTracker  
→ Controller  
→ ManualImuCoordinator::applyImuCorrection(...)  
→ Kinematics3RRS  
→ cmd_q_.push_latest(...)  
→ actuator thread wait_pop()  
→ ActuatorManager  
→ ServoDriver  

Manual path:

GUI valueChanged / ADS1115 callback  
→ store latest manual state  
→ control thread wait_pop()  
→ ManualImuCoordinator builds manual setpoint  
→ Kinematics3RRS  
→ cmd_q_.push_latest(...)  
→ actuator thread wait_pop()  
→ ActuatorManager  
→ ServoDriver  

Both paths are processed through the same control and actuation stages. The control thread maintains timing ownership in all modes.

---

## 7. Qt GUI Timing

Qt timers are used only for UI refresh and visualisation.

GUI interactions update stored manual state via valueChanged. The GUI does not generate actuator commands. Continuous command generation remains in the control thread.

---

## 8. IMU Policy in Manual Mode

Manual GUI input does not apply continuous IMU correction by default. Manual commands are generated directly from operator input.

IMU-assisted behaviour can be enabled through configured feedback modes.

---

## 9. Shutdown Behaviour

stop() performs:

- camera shutdown  
- backend shutdown  
- queue termination  
- worker thread join  
- actuator neutral/park handling  
- servo driver shutdown  

Queues notify blocked threads during shutdown, ensuring clean exit.

---

## 10. Summary

The runtime follows a consistent event-driven execution model:

- all worker threads block on kernel-backed primitives (poll, condition_variable)  
- all wakeups originate from external events (file descriptors, queue notifications, GPIO interrupts)  
- no component introduces independent timing loops or polling  

Control execution is centralised in a single thread. All inputs are reduced to state and processed within that thread before actuation.

This structure ensures:

- a single, deterministic control path  
- consistent behaviour across automatic and manual modes  
- separation between realtime processing and UI interaction  
- explicit ownership of timing and data flow

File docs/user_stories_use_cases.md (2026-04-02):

# User Stories and Use Cases

## Purpose

This document captures the user-facing goals supported by the  repository . All stories and use cases are grounded in the actual runtime behaviour visible in `src/app/CliController.cpp`, `src/qt/MainWindow.cpp`, and `src/system/SystemManager.hpp`.

---

## 1. User Stories

### Story 1 — Automatic tracking

As a user, I want the platform to automatically align toward the brightest light source so that the system performs autonomous solar tracking without manual intervention.

Supported by: automatic SEARCHING → TRACKING state transition on confidence threshold; continuous closed-loop updates in TRACKING state.

### Story 2 — Manual override via physical potentiometers

As a user, I want to manually position the platform using physical potentiometer inputs so that I can test, calibrate, or override the automatic mode without a computer.

Supported by: ADS1115 manual input backend; `ManualCommandSource::Pot`; MANUAL state with actuator path still active.

### Story 3 — Manual override via GUI sliders

As a user, I want to send explicit tilt and pan setpoints from the GUI so that I can position the platform precisely from the application window.

Supported by: pan and tilt `QSlider` controls in `MainWindow`; "Send manual setpoint" and "Zero" buttons; `ManualCommandSource::Gui`; `setManualSetpoint(tilt_rad, pan_rad)`.

### Story 4 — Manual override via CLI

As a developer or operator, I want to send manual setpoints and control the runtime from a terminal so that I can operate the system without the GUI.

Supported by: `CliController` commands: `manual`, `auto`, `set <tilt_rad> <pan_rad>`, `threshold <0..255>`, `quit`.

### Story 5 — Runtime state visibility

As a user, I want to see whether the system is IDLE, STARTUP, NEUTRAL, SEARCHING, TRACKING, MANUAL, STOPPING, or FAULT so that I always know the current operating mode.

Supported by: `registerStateObserver()` callback; `modeLabel_` and `statusLabel_` in `MainWindow`; CLI status output.

### Story 6 — Observe live pipeline signals

As a developer, I want to observe frame data, target estimates, platform setpoints, actuator commands, potentiometer voltages, and IMU readings in real time so that I can verify and debug pipeline behaviour.

Supported by the following registered observers in `MainWindow`:

| Observer | Data Exposed |
|---|---|
| `registerFrameObserver` | Raw camera frames → live preview |
| `registerEstimateObserver` | `SunEstimate` (position + confidence) |
| `registerSetpointObserver` | `PlatformSetpoint` (tilt, pan) |
| `registerCommandObserver` | `ActuatorCommand` (3-channel targets) → servo command plot |
| `registerManualObserver` | `ManualPotSample` (tilt voltage, pan voltage, sequence) |
| `registerImuObserver` | `ImuSample` (ax, ay, az) + computed tilt in degrees |
| `registerLatencyObserver` | Per-frame latency breakdown |

### Story 7 — Adjust tracking sensitivity at runtime

As a user, I want to adjust the brightness threshold used for target detection without restarting the application so that I can tune tracking sensitivity for changing light conditions.

Supported by: threshold `+`/`-` buttons in `MainWindow`; `threshold <0..255>` CLI command; `setTrackerThreshold()` in `SystemManager`.

### Story 8 — Switch manual input source at runtime

As a user, I want to switch between potentiometer control and GUI slider control without leaving manual mode so that I can hand off between physical and software inputs seamlessly.

Supported by: "Use Pots" / "Use GUI" buttons in `MainWindow`; `setManualCommandSource(ManualCommandSource::Pot/Gui)`.

### Story 9 — Safe shutdown

As a user, I want the platform to park safely and all backends to stop cleanly when I close the application so that the hardware is left in a known state.

Supported by: STOPPING state sequence (camera stop → thread join → neutral command → actuator stop → driver stop → IDLE); `park_on_stop = true` in default config; `signalfd` SIGINT/SIGTERM handling in `LinuxEventLoop`.

### Story 10 — Run without full hardware

As a developer or assessor, I want the system to run and process frames without a real camera or servo hardware so that software testing and non-hardware validation remain possible.

Supported by: `SimulatedPublisher` (`CameraBackend::Simulated`); `ServoDriver::StartupPolicy::LogOnly`; full software test suite in `test_core`.

---

## 2. Use Cases

### UC-1: Start automatic tracking

**Actor:** user

**Precondition:** application launched

1. `SystemManager::start()` is called
2. runtime enters STARTUP — camera validity checked, driver started, queues reset, threads started
3. runtime enters NEUTRAL — startup park applied at 41°
4. runtime enters SEARCHING — frames begin processing
5. `SunTracker` produces an estimate with confidence ≥ 0.4
6. runtime enters TRACKING — closed-loop actuator updates begin

**Postcondition:** platform continuously updates to follow the brightest target

---

### UC-2: Switch to manual mode and position the platform

**Actor:** user

**Precondition:** system in SEARCHING or TRACKING

**Path A — potentiometers (headless or GUI):**
1. user enters manual mode (`manual` CLI command or AUTO/MANUAL button)
2. runtime enters MANUAL — automatic controller disabled
3. ADS1115 delivers potentiometer samples via ALERT/RDY GPIO edge
4. `ManualImuCoordinator` maps voltages to setpoints via `ManualInputMapper`
5. setpoints pass through `Kinematics3RRS` → `ActuatorManager` → `ServoDriver`

**Path B — GUI sliders:**
1. user presses "Use GUI" button → `ManualCommandSource::Gui`
2. user adjusts pan/tilt sliders and presses "Send manual setpoint"
3. `setManualSetpoint(tilt_rad, pan_rad)` is called on `SystemManager`
4. same downstream path as Path A from step 5

**Path C — CLI:**
1. user types `set <tilt_rad> <pan_rad>`
2. `CliController` calls `setManualSetpoint()` directly

**Postcondition:** platform positioned at requested setpoint; automatic tracking suspended

---

### UC-3: Adjust tracking threshold at runtime

**Actor:** user / developer

**Precondition:** system running in any active state

1. user presses `+`/`-` threshold button in GUI, or types `threshold <value>` in CLI
2. `setTrackerThreshold(value)` updates the brightness cutoff in `SunTracker`
3. subsequent frames use the new threshold immediately

**Postcondition:** tracking sensitivity changed without restart

---

### UC-4: Observe live pipeline data

**Actor:** developer

**Precondition:** Qt GUI running; observers registered in `MainWindow`

The GUI displays the following in real time:

| Panel | Content |
|---|---|
| Live preview | Camera frames converted to Qt image |
| Mode / status labels | Current state, manual source |
| Manual input label | Tilt voltage, pan voltage, sequence counter |
| IMU label | ax, ay, az in m/s², computed tilt in degrees, valid flag |
| Servo command plot | 3-channel actuator targets over time |
| ADS1115 voltage plot | Tilt and pan potentiometer voltages over time |
| MPU6050 plot | Accelerometer axes over time |

Plot refresh rate: 33 ms timer (~30 Hz). Camera preview refresh rate: 33 ms timer.

---

### UC-5: Stop safely

**Actor:** user

**Precondition:** system in any active state

1. user presses STOP button, types `quit`/`exit`, or sends SIGINT/SIGTERM
2. runtime enters STOPPING
3. camera stops → frame queue stops and thread joins → command queue clears → neutral kinematics command issued → actuator thread stops → driver stops
4. runtime enters IDLE

**Postcondition:** platform parked at neutral position; all threads joined; hardware released

---

### UC-6: Run without hardware (simulated path)

**Actor:** developer / assessor

**Precondition:** built without libcamera/OpenCV, or libcamera unavailable at runtime

1. `defaultConfig()` selects `CameraBackend::Simulated` and `ServoDriver::StartupPolicy::LogOnly`
2. `SimulatedPublisher` generates synthetic frames at 30 Hz via `timerfd`-paced `poll()` loop
3. full pipeline runs — `SunTracker`, `Controller`, `ManualImuCoordinator`, `Kinematics3RRS`, `ActuatorManager` all execute normally
4. `ServoDriver` logs commands without writing to hardware

**Postcondition:** end-to-end software pipeline exercised without physical hardware

---

## 3. Summary

| Story | Interface |
|---|---|
| Automatic tracking | Runtime state machine |
| Manual via potentiometers | ADS1115 backend + MANUAL state |
| Manual via GUI sliders | `MainWindow` pan/tilt sliders |
| Manual via CLI | `set`, `manual`, `auto` commands |
| State visibility | State observer + GUI labels |
| Live signal observation | 7 registered observers + plots |
| Runtime threshold tuning | `+`/`-` buttons or `threshold` CLI |
| Manual source switching | "Use Pots" / "Use GUI" buttons |
| Safe shutdown | STOPPING sequence + park on stop |
| Simulated fallback | `SimulatedPublisher` + `LogOnly` servo |

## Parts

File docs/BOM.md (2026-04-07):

# Bill of Materials (BOM) — Solar Stewart Tracker

## 1. Hardware Components

| Item No. | Component | Specification / Model | Qty | Supplier | Unit Cost (£) | Total (£) | Notes |
|---|---|---|-----|---|---|---|---|
| 1 | Raspberry Pi 5 | 8GB Model | 1 | Lab / Personal | 80.00 | 80.00 | Main controller |
| 2 | IMX219 Camera | 8MP CSI Camera Module | 1 | Amazon | 25.00 | 25.00 | Vision input |
| 3 | PCA9685 PWM Driver | 16-channel I2C PWM | 1 | Amazon | 12.00 | 12.00 | Servo control |
| 4 | High-Torque Servo | RDS3230 or equivalent | 3 | Amazon | 15.00 | 45.00 | 3RRS actuators |
| 5 | External Power Supply | 5–6V High Current | 1 | Amazon | 20.00 | 20.00 | Servo supply |
| 6 | Breadboard & Wiring | Jumper wires, headers | 1 set | Lab | 10.00 | 10.00 | Prototyping |
| 7 | Structural Frame | Acrylic / 3D Printed | 1 | Self-fabricated | 15.00 | 15.00 | Platform support |
| 8 | Fasteners & Mounts | Screws, brackets | Assorted | Hardware Store | 10.00 | 10.00 | Mechanical assembly |

---

## 2. Software Dependencies

| Software | Purpose | Cost |
|---|---|---|
| C++17 | Core implementation | Free |
| CMake | Build system | Free |
| OpenCV | Vision processing | Free |
| libcamera | Camera backend (Pi) | Free |
| GitHub | Version control | Free |

---

## 3. Cost Summary

| Category | Cost (£) |
|---|---|
| Electronics | 182.00 |
| Mechanical | 25.00 |
| Miscellaneous | 10.00 |
| **Total Hardware Cost** | **£217.00** |

---

## 4. Budget Assessment

- Total estimated cost: **£217.00**
- Major cost drivers:
  - Raspberry Pi
  - High-torque servos
  - Camera module

---

## 5. Design Considerations

- External servo power supply used to prevent brownout.
- PWM driver isolates timing from Raspberry Pi CPU.
- Modular design allows hardware substitution without software redesign.

---

## 6. Traceability to Architecture

| Subsystem | Hardware Used |
|---|---|
| Vision (T1/T2) | IMX219 Camera |
| Control (T2) | Raspberry Pi 5 |
| Actuation (T3) | PCA9685 + Servos |
| Safety Layer | ActuatorManager (software) |
| Logging | Console / File logger |

---

## 7. Reproducibility Notes

All components are commercially available.
Part numbers and specifications allow replication of the system.
Mechanical components can be 3D printed using standard PLA.

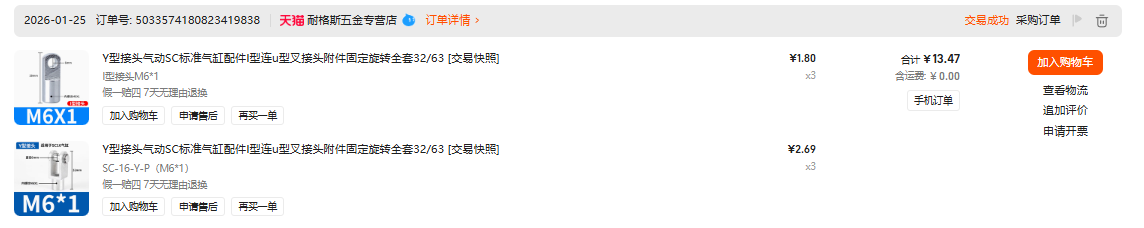
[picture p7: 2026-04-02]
datasheets/component/rotary_joint_y_sc_set.png

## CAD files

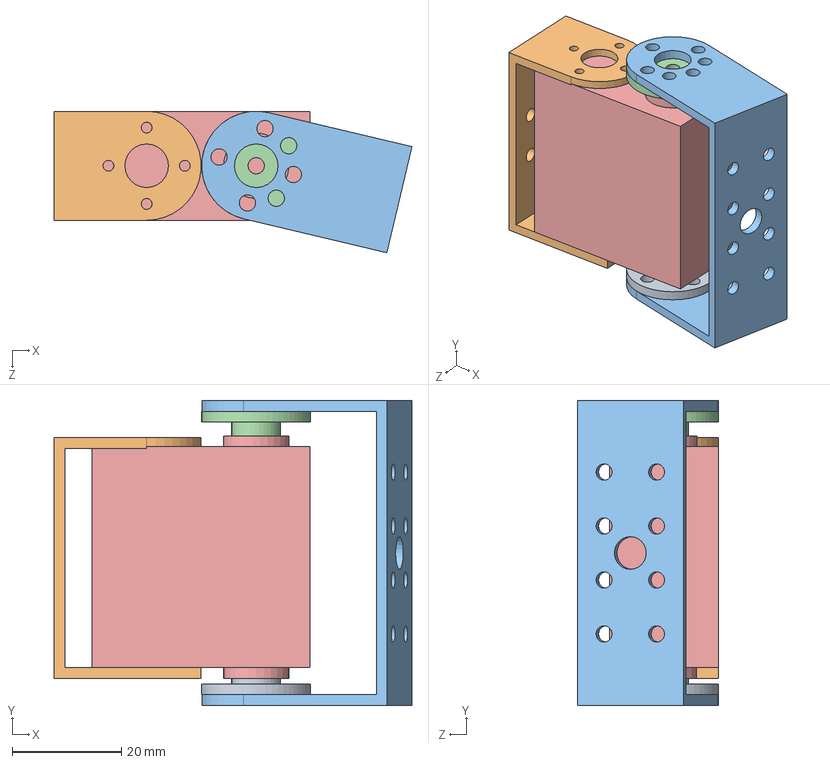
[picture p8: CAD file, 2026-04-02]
diagrams/mechanical model/3rrs/Dual-axis servo.SLDASM
65.7 x 56.0 x 26.0 mm
3230 Servo Motor
Real-axis steering wheel
Double-axis wide U bracket
Double-axis narrow U bracket
Imaginary axis steering wheel

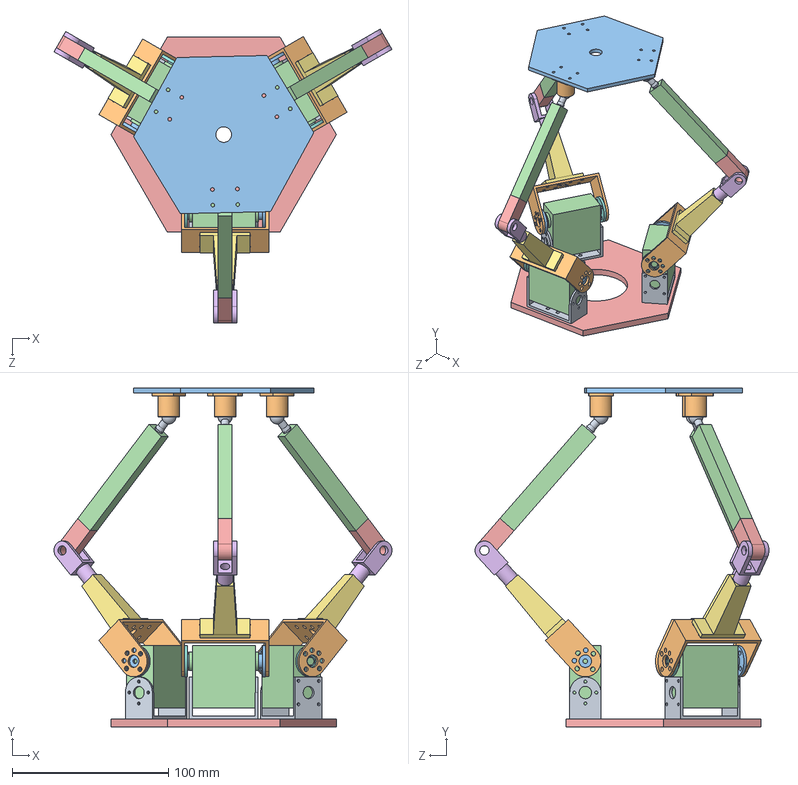
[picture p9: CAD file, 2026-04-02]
diagrams/mechanical model/3rrs/di.SLDASM
216.4 x 217.0 x 188.2 mm
The static platform below
3230 Servo Motor x 3
Real-axis steering wheel x 3
Double-axis wide U bracket x 3
Double-axis narrow U bracket x 3
Imaginary axis steering wheel x 3
L1 arm x 3
sc-16-yp x 3
I M6 x 3
L2 arm x 3
The motion platform above
ball head neck x 3
ball head x 3

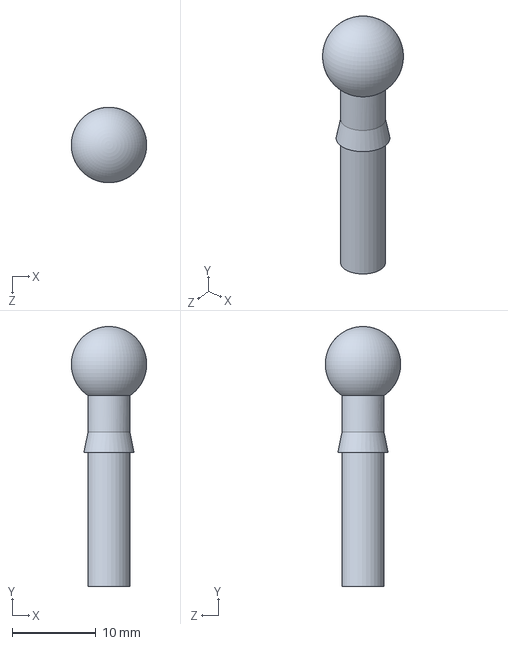
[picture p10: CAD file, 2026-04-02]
diagrams/mechanical model/3rrs/ball head.SLDPRT
8.99 x 31.0 x 8.99 mm

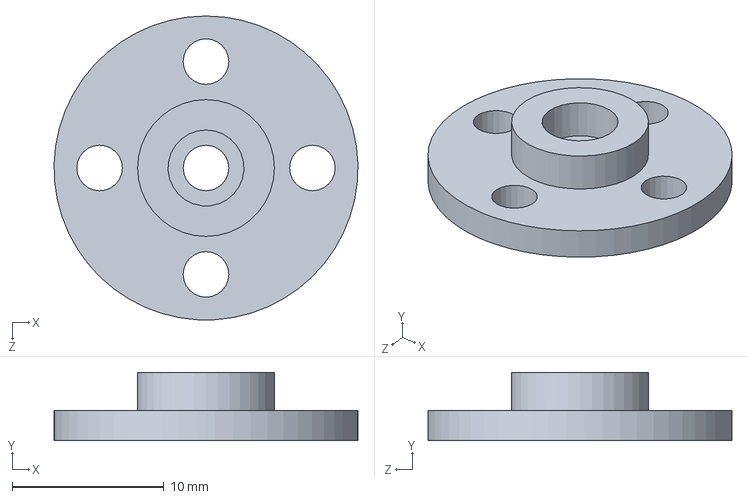
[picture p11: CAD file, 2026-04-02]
diagrams/mechanical model/3rrs/Real-axis steering wheel.SLDPRT
20.0 x 4.50 x 20.0 mm

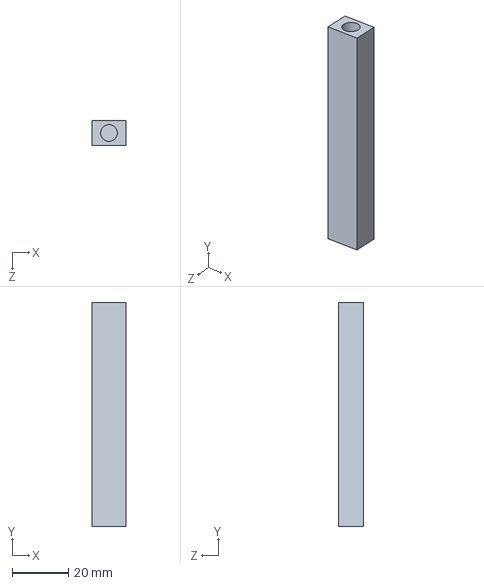
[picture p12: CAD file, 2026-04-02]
diagrams/mechanical model/3rrs/L2 arm.SLDPRT
12.0 x 80.0 x 9.00 mm

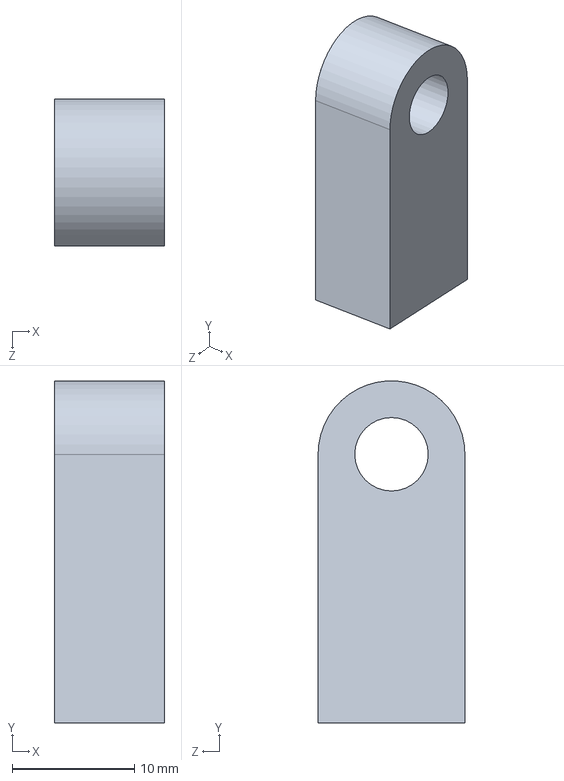
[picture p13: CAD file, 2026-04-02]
diagrams/mechanical model/3rrs/I M6.SLDPRT
9.00 x 27.9 x 12.0 mm

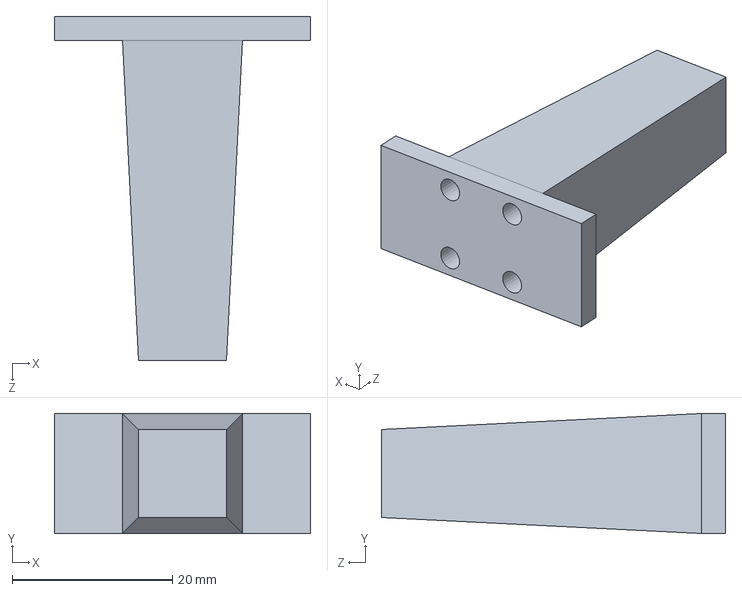
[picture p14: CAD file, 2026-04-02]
diagrams/mechanical model/3rrs/L1 arm.SLDPRT
32.0 x 15.0 x 43.0 mm

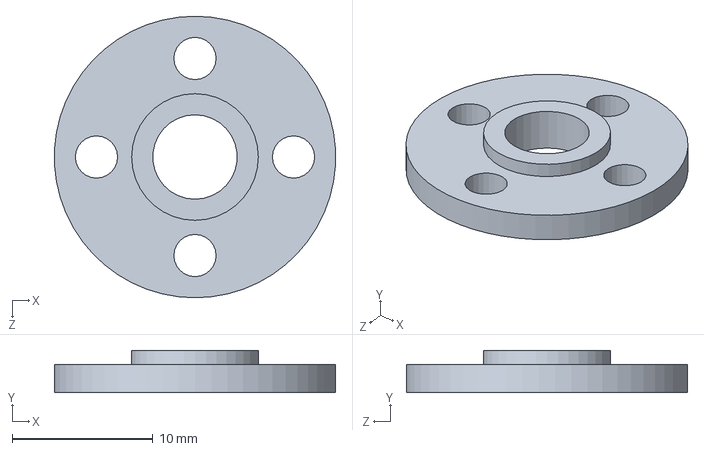
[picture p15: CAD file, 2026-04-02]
diagrams/mechanical model/3rrs/Imaginary axis steering wheel.SLDPRT
20.0 x 3.00 x 20.0 mm

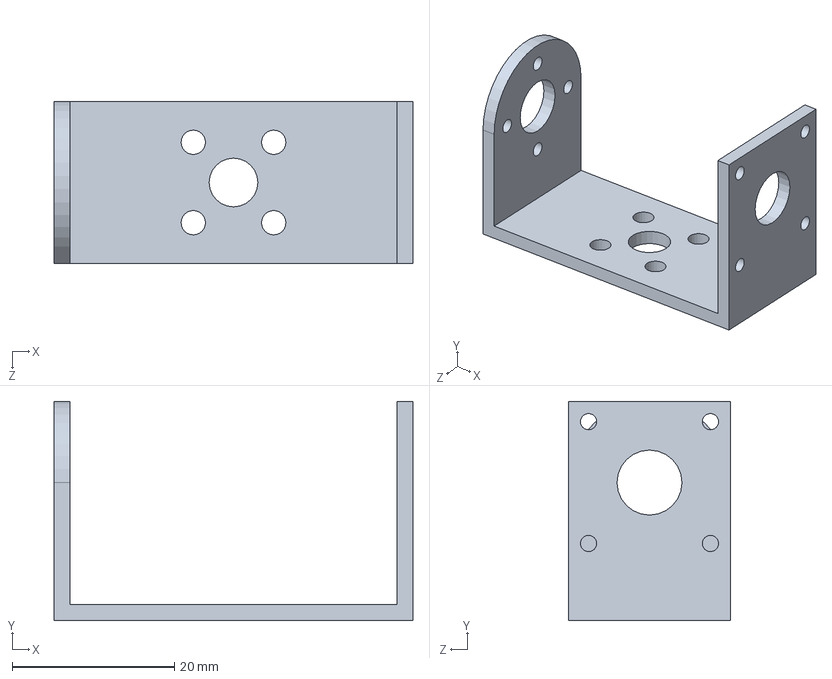
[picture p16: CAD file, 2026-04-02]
diagrams/mechanical model/3rrs/Double-axis narrow U bracket.SLDPRT
44.2 x 27.0 x 20.0 mm

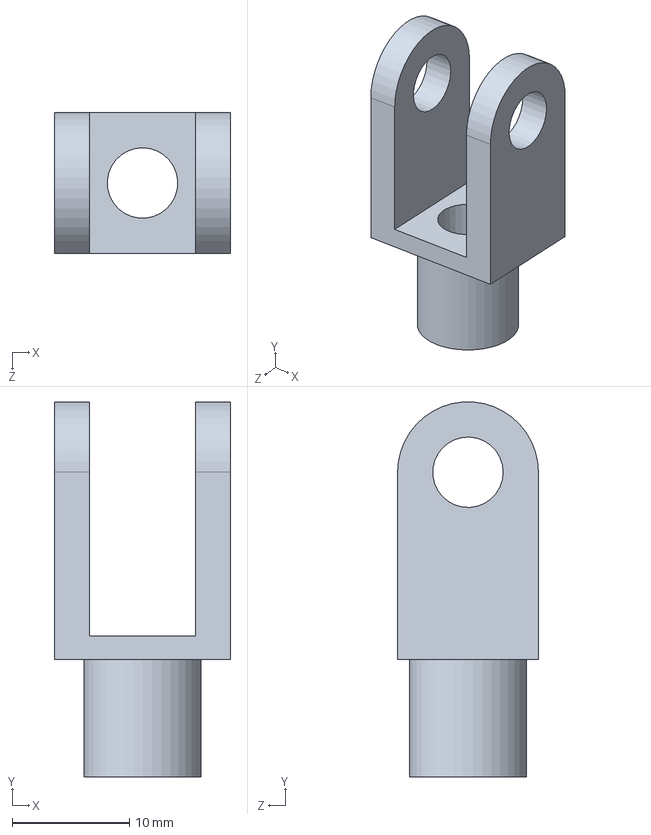
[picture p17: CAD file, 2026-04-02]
diagrams/mechanical model/3rrs/sc-16-yp.SLDPRT
15.0 x 31.9 x 12.0 mm

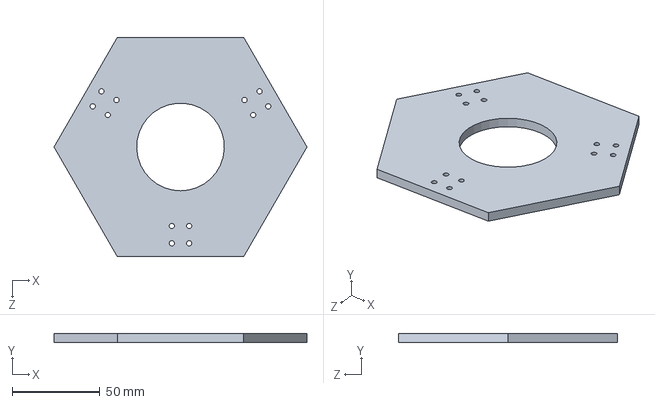
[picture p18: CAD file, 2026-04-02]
diagrams/mechanical model/3rrs/The static platform below.SLDPRT
144.3 x 5.00 x 125.0 mm

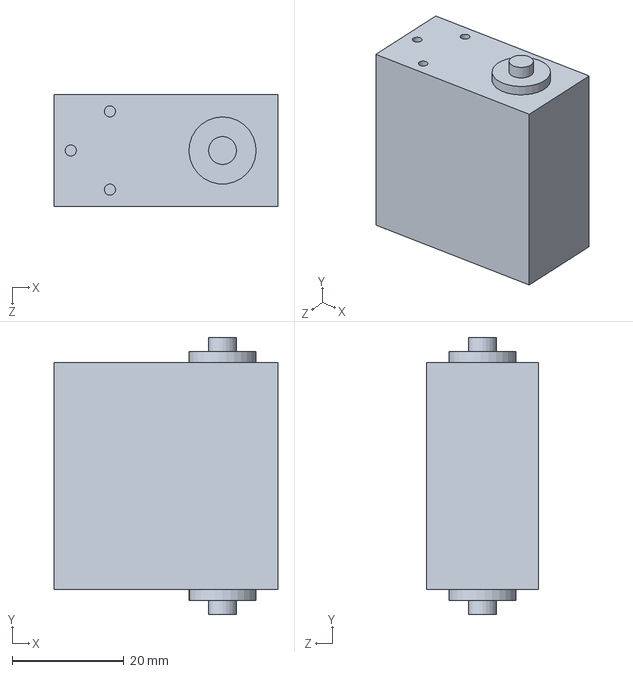
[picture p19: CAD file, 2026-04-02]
diagrams/mechanical model/3rrs/3230 Servo Motor.SLDPRT
40.0 x 49.5 x 20.0 mm

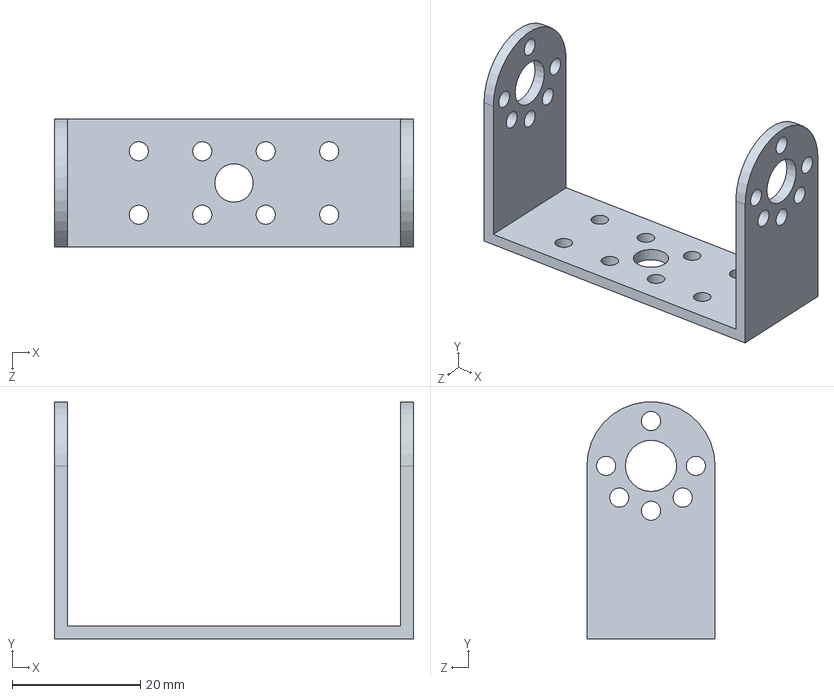
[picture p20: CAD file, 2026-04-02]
diagrams/mechanical model/3rrs/Double-axis wide U bracket.SLDPRT
56.0 x 37.0 x 20.0 mm

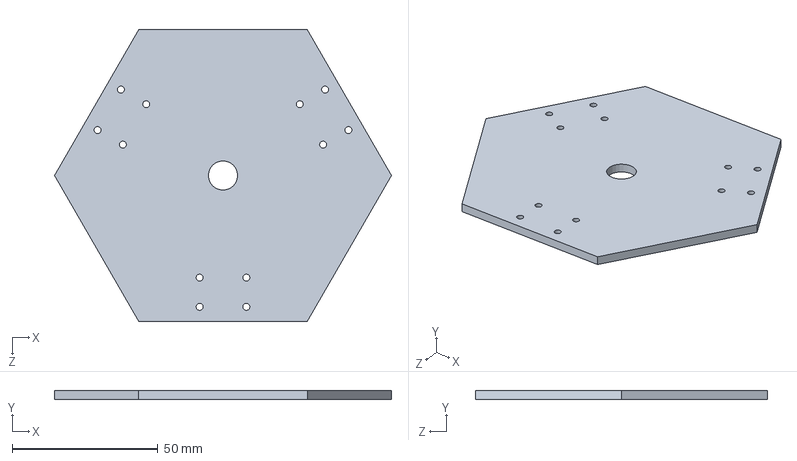
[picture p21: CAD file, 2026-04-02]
diagrams/mechanical model/3rrs/The motion platform above.SLDPRT
115.5 x 3.00 x 100.0 mm

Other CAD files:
diagrams/mechanical model/3rrs/Raspberry Pi box sketch version.SLDPRT
diagrams/mechanical model/3rrs/ball head neck.SLDPRT

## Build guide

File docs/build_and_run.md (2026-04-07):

# Build and Run

This file gives the exact repository setup, submodule checkout, build, test, and run commands for the  project .

---

## Cloning

To clone with all submodules in one step, run:

```bash
git clone --recurse-submodules https://github.com/Real-Time-Stewart-Solar-Tracker/Solar-Stewart-Tracker.git
cd Solar-Stewart-Tracker
```

If you already cloned without submodules, run:

```bash
git submodule update --init --recursive
```

---

## External repositories used by this project

The project uses these external repositories as git submodules under `external/`, use these commands if you dont have them:

```bash
git submodule add https://github.com/berndporr/libcamera2opencv.git external/libcamera2opencv
git submodule add https://github.com/berndporr/libgpiod_event_demo.git external/libgpiod_event_demo
```

After adding them, fetch their contents with:

```bash
git submodule update --init --recursive
```

To verify they are present, run:

```bash
git submodule status
ls external
```

If you ever need to refresh them to the commits recorded by the main repository, run:

```bash
git submodule sync --recursive
git submodule update --init --recursive --checkout
```

To pull the latest remote changes for the submodules:

```bash
git submodule update --remote --recursive
```

---

## If the external folders are missing

If the repository was copied manually and the `external/` repositories are not populated, use:

```bash
git submodule update --init --recursive
```

That will place the repositories at these exact paths:

```text
external/libcamera2opencv
external/libgpiod_event_demo
```

---

## Linux dependencies

### libgpiod v2 — required, must be built from source

The project requires the C++ bindings introduced in libgpiod v2. The `apt` package on Raspberry Pi OS provides v1.x only. Build v2.2.2 from source:

```bash
sudo apt install -y autoconf autoconf-archive automake libtool wget xz-utils

cd /tmp
wget https://mirrors.edge.kernel.org/pub/software/libs/libgpiod/libgpiod-2.2.2.tar.xz
tar -xf libgpiod-2.2.2.tar.xz
cd libgpiod-2.2.2
./configure --prefix=/usr/local --enable-tools --enable-bindings-cxx
make -j$(nproc)
sudo make install
sudo ldconfig
```

Verify:
```bash
pkg-config --modversion libgpiod   # should print 2.2.2
```

### Core build dependencies

```bash
sudo apt update
sudo apt install -y build-essential cmake ninja-build git pkg-config
# Note: libgpiod-dev via apt provides v1.x only. This project requires v2.
# See the libgpiod v2 build-from-source instructions below.
```

### Optional Qt GUI dependencies

```bash
sudo apt install -y qtbase5-dev libqt5charts5-dev qt5-qmake
```

### Optional OpenCV and libcamera dependencies

```bash
sudo apt install -y libopencv-dev libcamera-dev
```

### Optional hardware tools

```bash
sudo apt install -y i2c-tools
```

### Optional documentation tools

```bash
sudo apt install -y doxygen graphviz
```

---

## CMake options used by this project

```text
SOLAR_ENABLE_TESTS=ON        default
SOLAR_ENABLE_HW_TESTS=OFF    default
SOLAR_ENABLE_QT=ON           default
SOLAR_TRY_LIBCAMERA=ON       default
SOLAR_TRY_OPENCV=ON          default
SOLAR_ENABLE_COVERAGE=OFF    default
```

---

## Standard release build

```bash
cmake -S . -B build -G Ninja -DCMAKE_BUILD_TYPE=Release
cmake --build build --parallel
```

If you do not want to use Ninja:

```bash
cmake -S . -B build -DCMAKE_BUILD_TYPE=Release
cmake --build build --parallel
```

---

## Minimal headless build

This disables the optional GUI, libcamera, and OpenCV paths:

```bash
cmake -S . -B build   -G Ninja   -DCMAKE_BUILD_TYPE=Release   -DSOLAR_ENABLE_QT=OFF   -DSOLAR_TRY_LIBCAMERA=OFF   -DSOLAR_TRY_OPENCV=OFF

cmake --build build --parallel
```

---

## Build with hardware tests enabled

```bash
cmake -S . -B build   -G Ninja   -DCMAKE_BUILD_TYPE=Debug   -DSOLAR_ENABLE_TESTS=ON   -DSOLAR_ENABLE_HW_TESTS=ON   -DSOLAR_ENABLE_QT=OFF   -DSOLAR_TRY_LIBCAMERA=OFF   -DSOLAR_TRY_OPENCV=OFF

cmake --build build --parallel
```

This same configuration is also wrapped by the repository helper script:

```bash
./scripts/build_pi_debug.sh build
```

---

## Main executables

After a successful build, the main runtime targets are:

```text
build/solar_tracker
build/src/qt/solar_tracker_qt   (only if Qt5 Widgets and Qt5 Charts were found)
```

---

## Run the application

### Headless application

```bash
./build/solar_tracker
```

### Qt GUI application

```bash
./build/solar_tracker_qt
```

---

## Run the software tests

```bash
ctest --test-dir build --output-on-failure
```

Repository helper script:

```bash
./scripts/test_core.sh build
```

---

## Run hardware-labelled tests on Raspberry Pi

The helper script sets default hardware environment variables and then runs CTest with the `hw` label.

```bash
./scripts/test_pi_hw.sh build
```

Equivalent explicit form:

```bash
export SOLAR_RUN_CAMERA_HW_TESTS=1
export SOLAR_RUN_I2C_HW_TESTS=1
export SOLAR_I2C_DEV=/dev/i2c-1
ctest --test-dir build -L hw --output-on-failure
```

---

## Manual hardware smoke tests

These are for controlled hardware checks and should only be run on the target machine with the hardware connected safely.

```bash
./build/src/actuators/tests/test_pca9685
./build/tests/test_servodriver
```

---

## Typical Raspberry Pi workflow

```bash
git clone --recurse-submodules https://github.com/Real-Time-Stewart-Solar-Tracker/Solar-Stewart-Tracker.git
cd Solar-Stewart-Tracker

git submodule update --init --recursive

cmake -S . -B build   -G Ninja   -DCMAKE_BUILD_TYPE=Release   -DSOLAR_ENABLE_QT=OFF   -DSOLAR_ENABLE_HW_TESTS=ON

cmake --build build --parallel

ctest --test-dir build --output-on-failure
./build/solar_tracker
```

---

## Clean rebuild

If the build directory becomes stale, rebuild from scratch:

```bash
rm -rf build build
git submodule sync --recursive
git submodule update --init --recursive
cmake -S . -B build -G Ninja -DCMAKE_BUILD_TYPE=Release
cmake --build build --parallel
ctest --test-dir build --output-on-failure
```

---

## Notes

- Use `--recurse-submodules` on the first clone so the external repositories are checked out immediately.
- If someone cloned the repository without submodules, `git submodule update --init --recursive` is the required recovery step.
- Keep the external repositories at the paths under `external/` so the build system can find them consistently.

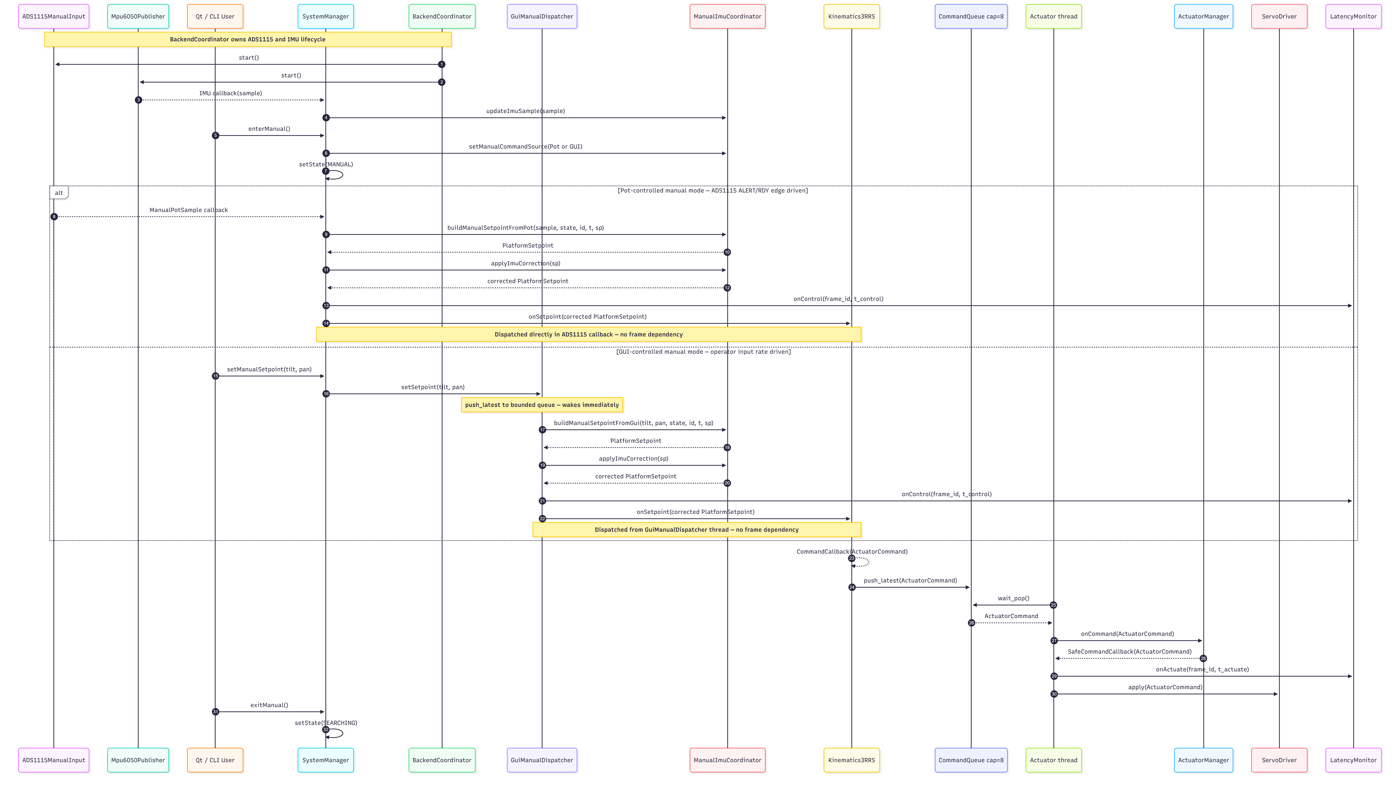
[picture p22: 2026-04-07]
diagrams/Sequence Diagram — Manual Input + IMU Update Paths.png

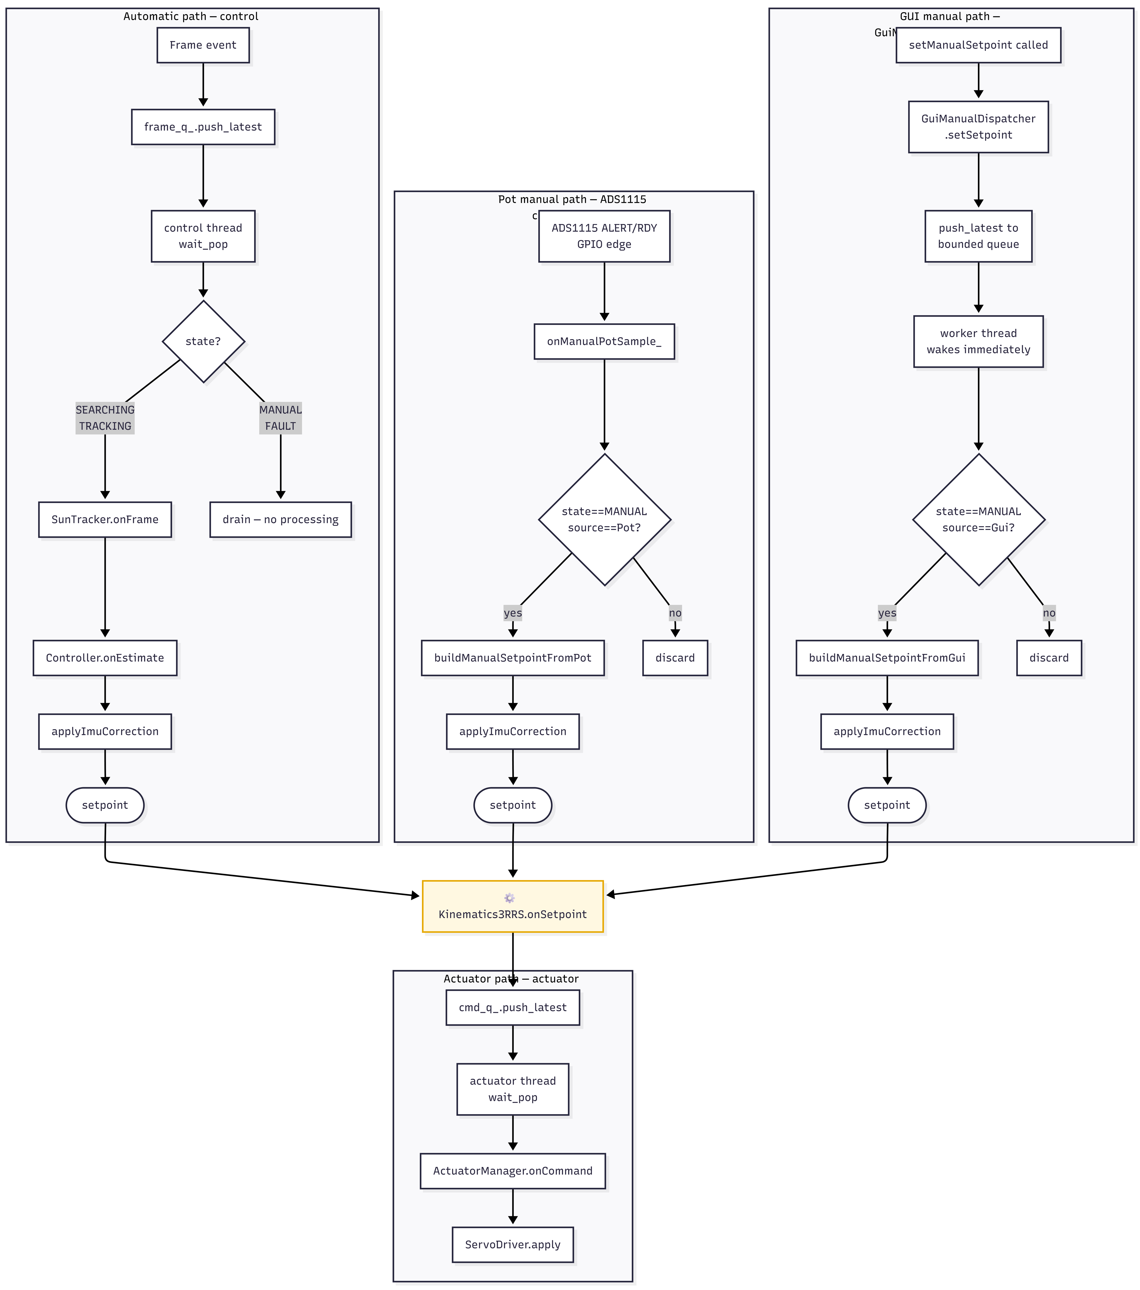
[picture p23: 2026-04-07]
diagrams/Automatic Processing vs Manual Processing.png

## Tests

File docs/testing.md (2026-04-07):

# Testing and Reliability Strategy

This document describes the testing setup implemented in the repository source. Tests are co-located with their modules under `src/*/tests/` and wired into CTest via each module's own `CMakeLists.txt`.

The test approach is intentionally lightweight:

- a small custom runner is used instead of an external framework
- named checks are registered with CTest via each module's `CMakeLists.txt`
- core logic is exercised with deterministic inputs
- hardware-adjacent tests are separated behind an explicit build option
- fake I2C support is used where that improves automation

---

## 1. Testing Approach

The test strategy is based on the following principles:

- keep core logic testable without physical hardware
- isolate vision, control, queueing, kinematics, and system state as deterministic software tests
- make hardware-adjacent tests opt-in via `-DSOLAR_ENABLE_HW_TESTS=ON`
- expose individual named cases through CTest
---

## 2. Test Framework

The repository does not use GoogleTest, Catch2, or another external framework. Instead it uses a small custom framework at `src/tests/support/`:

| File | Purpose |
|---|---|
| `src/tests/support/test_main.cpp` | Runner entry point |
| `src/tests/support/test_common.hpp` | `TEST_CASE(...)` registration and `REQUIRE(...)` assertion helper |
| `src/tests/support/FakeI2CDevice.hpp` | Fake I2C device for hardware-adjacent software tests |

Each test executable is built by linking `test_main.cpp` together with one or more test source files.

### Running an executable directly

```bash
# Run all tests compiled into an executable
./build/src/control/tests/test_control
```

With no arguments an executable runs every test compiled into it. CTest remains the primary interface for selecting and running tests. Individual test binaries can also be run directly from the build tree, but their command-line interfaces are not assumed to be uniform across all executables.

---

## 3. Test Executables and Module Structure

Tests are co-located with source. Each module's `CMakeLists.txt` conditionally includes its `tests/` subdirectory.

### Always-built executables (`SOLAR_ENABLE_TESTS=ON`)

| Executable | Module | Source path |
|---|---|---|
| `test_common_core` | `src/common` | `src/common/tests/` |
| `test_vision` | `src/vision` | `src/vision/tests/` |
| `test_control` | `src/control` | `src/control/tests/` |
| `test_actuators` | `src/actuators` | `src/actuators/tests/` |
| `test_system` | `src/system` | `src/system/tests/` |

### Hardware-adjacent executables (`SOLAR_ENABLE_TESTS=ON` and `SOLAR_ENABLE_HW_TESTS=ON`)

| Executable | Module | Source path |
|---|---|---|
| `test_pca9685` | `src/actuators` | `src/actuators/tests/` |
| `test_servodriver` | `src/actuators` | `src/actuators/tests/` |
| `test_mpu6050_publisher` | `src/sensors` | `src/sensors/tests/` |
| `test_linux_i2c_hw` | `src/hal` | `src/hal/tests/` |

---

## 4. CTest Integration

CTest is used and named cases are registered with `add_test(...)` in each module's `CMakeLists.txt`, allowing failures to be reported at individual test-case level.

```bash
# Linux / single-config generators
ctest --test-dir build --output-on-failure

# Windows / multi-config generators
ctest --test-dir build -C Release --output-on-failure
```

### Test count

| Condition | CTest entries |
|---|---:|
| `SOLAR_ENABLE_TESTS=ON` only | 55 |
| `SOLAR_ENABLE_TESTS=ON` and `SOLAR_ENABLE_HW_TESTS=ON` | 75 |

---

## 5. CTest Cases by Module

### 5.1 SunTracker

Executable: `test_vision` — Source: `src/vision/tests/test_suntracker.cpp`

| CTest Case | What It Covers |
|---|---|
| `SunTracker_DetectsSingleBrightPixel` | Bright target detection |
| `SunTracker_NoBrightPixels_ProducesZeroConfidence` | Zero-confidence when no bright region exists |
| `SunTracker_WeightedCentroid_IsCorrect` | Weighted centroid on deterministic synthetic input |

### 5.2 Controller

Executable: `test_control` — Source: `src/control/tests/test_controller.cpp`

| CTest Case | What It Covers |
|---|---|
| `Controller_LowConfidence_NoMotion` | Confidence gating |
| `Controller_WithinDeadband_NoMotion` | Deadband behaviour |
| `Controller_OutsideDeadband_ProducesMotion` | Non-zero control response |
| `Controller_OutputClamped` | Output saturation/clamping |

### 5.3 Kinematics3RRS

Executable: `test_control` — Source: `src/control/tests/test_kinematics.cpp`

| CTest Case | What It Covers |
|---|---|
| `Kinematics3RRS_outputs_in_range_for_moderate_setpoint` | Output sanity and servo range |
| `Kinematics3RRS_neutral_setpoint_produces_near_neutral_angles` | Neutral symmetry |
| `Kinematics3RRS_frame_id_forwarded_through_callback` | Frame ID propagation |
| `Kinematics3RRS_small_setpoint_changes_produce_small_output_changes` | Continuity for small input changes |
| `Kinematics3RRS_zero_setpoint_after_valid_does_not_trigger_fallback` | Zero setpoint does not degrade |
| `Kinematics3RRS_large_reachable_setpoint_stays_in_range` | Workspace boundary check |
| `Kinematics3RRS_invalid_geometry_surfaces_error_status` | Invalid-geometry error surfacing |
| `Kinematics3RRS_first_invalid_then_second_invalid_stays_in_range` | Consecutive invalid configs safe |
| `Kinematics3RRS_good_then_bad_geometry_falls_back_to_last_valid` | Fallback after previously valid state |

### 5.4 ManualInputMapper

Executable: `test_control` — Source: `src/control/tests/test_manual_input_mapper.cpp`

| CTest Case | What It Covers |
|---|---|
| `ManualInputMapper_CentreVoltage_MapsToZeroCommand` | Centre mapping |
| `ManualInputMapper_LowAndHighVoltages_MapToMinusAndPlusOne` | Full-range mapping |
| `ManualInputMapper_InversionFlags_FlipDirections` | Inversion behaviour |
| `ManualInputMapper_Deadband_ZerosSmallInputsAndRescalesBeyondDeadband` | Deadband behaviour |
| `ManualInputMapper_OutOfRangeVoltages_AreClampedSafely` | Safe clamping of out-of-range inputs |

### 5.5 ImuFeedbackMapper

Executable: `test_control` — Source: `src/control/tests/test_imu_feedback_mapper.cpp`

| CTest Case | What It Covers |
|---|---|
| `ImuFeedbackMapper_ZeroTilt_ProducesZeroCorrection` | Zero-tilt response |
| `ImuFeedbackMapper_PositiveTilt_ProducesNegativeCorrection` | Correction sign |
| `ImuFeedbackMapper_NegativeTilt_ProducesPositiveCorrection` | Symmetry across tilt direction |
| `ImuFeedbackMapper_RuntimeGainChange_TakesEffectImmediately` | Immediate effect of runtime gain changes |

### 5.6 ImuTiltEstimator

Executable: `test_control` — Source: `src/control/tests/test_imu_tilt_estimator.cpp`

| CTest Case | What It Covers |
|---|---|
| `ImuTiltEstimator_InvalidSample_ReturnsZero` | Invalid sample handling |
| `ImuTiltEstimator_LevelGravity_ReturnsZeroTilt` | Level orientation |
| `ImuTiltEstimator_PositiveAx_WithGravity_ReturnsPositiveTilt` | Positive tilt reconstruction |
| `ImuTiltEstimator_NegativeAx_WithGravity_ReturnsNegativeTilt` | Negative tilt reconstruction |
| `ImuTiltEstimator_DegenerateDenominator_ReturnsZero` | Degenerate denominator protection |

### 5.7 ActuatorManager

Executable: `test_actuators` — Source: `src/actuators/tests/test_actuatormanager.cpp`

| CTest Case | What It Covers |
|---|---|
| `ActuatorManager_first_command_is_saturated_without_history_limit` | First-command behaviour |
| `ActuatorManager_subsequent_commands_are_rate_limited_per_channel` | Per-channel rate limiting |
| `ActuatorManager_saturation_happens_before_history_update` | Saturation ordering |
| `ActuatorManager_resetHistory_disables_slew_limit_for_next_command` | History reset behaviour |
| `ActuatorManager_zero_or_negative_step_holds_previous_value` | Behaviour when allowed step is zero or negative |

### 5.8 ThreadSafeQueue

Executable: `test_common_core` — Source: `src/common/tests/test_threadsafequeue.cpp`

| CTest Case | What It Covers |
|---|---|
| `ThreadSafeQueue_FIFO_basic` | FIFO ordering |
| `ThreadSafeQueue_bounded_push_strict_rejects_when_full` | Strict bounded insertion |
| `ThreadSafeQueue_bounded_push_latest_drops_oldest` | Freshest-value overwrite semantics |
| `ThreadSafeQueue_wait_pop_blocks_then_wakes` | Blocking wake-up behaviour |
| `ThreadSafeQueue_stop_unblocks_waiters_and_returns_nullopt_when_empty` | Stop/unblock behaviour |

### 5.9 LatencyMonitor

Executable: `test_common_core` — Source: `src/common/tests/test_latency_monitor.cpp`

| CTest Case | What It Covers |
|---|---|
| `LatencyMonitor_accepts_ordered_timestamps_and_prints` | Ordered timestamp handling |
| `LatencyMonitor_handles_out_of_order_calls_without_crashing` | Out-of-order robustness |
| `LatencyMonitor_prunes_inflight_frames_under_pressure_without_crashing` | In-flight frame pruning under pressure |

> **Note:** A fourth test (`LatencyMonitor_reports_jitter_over_multiple_records`) is compiled into `test_common_core` but is not individually registered as a CTest entry.

### 5.10 SystemManager

Executable: `test_system`  
Sources: `src/system/tests/test_systemmanager_statemachine.cpp`, `src/system/tests/test_systemmanager_imu_shadow.cpp`

| CTest Case | What It Covers |
|---|---|
| `SystemManager_start_to_searching_then_tracking_on_bright_frame` | Startup progression and tracking-state transition |
| `SystemManager_manual_mode_emits_commands` | Manual mode command emission |
| `SystemManager_start_with_null_camera_enters_fault_and_fails` | Fault entry on null camera |
| `SystemManager_start_when_camera_start_fails_enters_fault` | Fault entry on camera start failure |
| `SystemManager_ImuShadow_StartsWithoutImuBackend` | IMU shadow-mode startup without backend |
| `SystemManager_ImuDisabled_StartsNormally` | IMU disabled mode starts normally |
| `SystemManager_ImuShadow_ManualModeTransitions` | Shadow mode does not block manual transitions |
| `SystemManager_ImuShadow_NullCameraEntersFault` | Null camera enters FAULT |
| `SystemManager_ImuShadow_CameraStartFailureEntersFault` | Camera start failure enters FAULT |
| `SystemManager_ImuShadow_StopFromIdleIsIdempotent` | Stop from IDLE is a safe no-op |
| `SystemManager_ImuLive_StartsNormallyWhenNoImuBackendConfigured` | Live mode degrades gracefully without IMU |
| `SystemManager_ImuShadow_StateObserverReceivesTransitions` | State observer receives startup transitions |

---

## 6. Hardware-Adjacent Tests (`SOLAR_ENABLE_HW_TESTS=ON`)

### 6.1 PCA9685

Executable: `test_pca9685` — Source: `src/actuators/tests/test_pca9685.cpp`

| CTest Case | What It Covers |
|---|---|
| `PCA9685_default_constructor_is_not_started` | Safe default construction |
| `PCA9685_set_pulse_us_fails_before_start` | Pre-start failure handling |
| `PCA9685_invalid_channel_rejected_even_if_not_started` | Channel validation |
| `PCA9685_stop_is_safe_when_not_started` | Safe stop before startup |

### 6.2 ServoDriver

Executable: `test_servodriver` — Source: `src/actuators/tests/test_servodriver.cpp`

| CTest Case | What It Covers |
|---|---|
| `ServoDriver_log_only_mode_starts_without_hardware` | Startup policy across hardware modes |
| `ServoDriver_require_hardware_fails_fast_when_unavailable` | Fast failure on missing required hardware |
| `ServoDriver_prefer_hardware_falls_back_to_log_only_when_unavailable` | Fallback to log-only mode |
| `ServoDriver_require_hardware_with_injected_pca_enters_hardware_mode` | Injected PCA path |
| `ServoDriver_apply_while_stopped_writes_nothing` | No writes while stopped |
| `ServoDriver_start_parks_to_neutral_when_enabled` | Parking on start |
| `ServoDriver_stop_parks_to_neutral_when_enabled` | Parking on stop |
| `ServoDriver_apply_clamps_and_writes_channels` | Command clamping and channel writes |
| `ServoDriver_inverted_channel_maps_correctly` | Inverted channel mapping |

### 6.3 Mpu6050Publisher

Executable: `test_mpu6050_publisher` — Source: `src/sensors/tests/test_mpu6050_publisher.cpp`

| CTest Case | What It Covers |
|---|---|
| `Mpu6050Publisher_StartFailsWithoutCallback` | Callback pre-condition (software) |
| `Mpu6050Publisher_StartFailsIfWhoAmIDoesNotMatch` | WHO_AM_I identity check (software) |
| `Mpu6050Publisher_InitialisesExpectedRegisters` | Six init registers written before GPIO (software) |
| `Mpu6050Publisher_StartSucceedsAndStopClosesDevice` | Full start/stop lifecycle (hardware, GPIO 27) |
| `Mpu6050Publisher_DoubleStartReturnsFalse` | Double-start guard (hardware, GPIO 27) |
| `Mpu6050Publisher_StartupDiscardPreventsEarlyCallbacks` | Startup discard window (hardware, GPIO 27) |

### 6.4 Linux I2C Hardware Check

Executable: `test_linux_i2c_hw` — Source: `src/hal/tests/test_linux_i2c_hw.cpp`

| CTest Case | Labels | Notes |
|---|---|---|
| `LinuxI2C_PCA9685_hw_init_and_write` | `hw;i2c;integration` | Skips cleanly (`SKIP_RETURN_CODE 77`) when hardware is unavailable |

---

## 7. What the Tests Demonstrate

- bright-target detection and centroid logic
- controller gating, deadband, and output clamping
- bounded queue semantics and blocking wake-up behaviour
- actuator command limiting and history behaviour
- kinematics validity, continuity, and fallback behaviour
- latency-monitor robustness
- system-manager startup, manual-mode, and selected fault paths
- manual input mapping
- IMU tilt estimation and IMU feedback mapping
- selected startup and mapping behaviour of PCA9685, ServoDriver, and MPU6050 publisher (when hardware-adjacent tests are enabled)

---

## 8. Practical Commands

```bash
# Run all CTest-registered checks
ctest --test-dir build --output-on-failure -LE hw

# Run hardware tests (requires hardware connected)
SOLAR_RUN_I2C_HW_TESTS=1 ctest --test-dir build --output-on-failure

# Run one CTest entry by name
ctest --test-dir build --output-on-failure -R Controller_OutputClamped

# Run individual module executables directly
./build/src/vision/tests/test_vision
./build/src/control/tests/test_control
./build/src/common/tests/test_common_core
./build/src/actuators/tests/test_actuators
./build/src/system/tests/test_system

# Enable and build hardware-adjacent tests
cmake -S . -B build -G Ninja -DSOLAR_ENABLE_TESTS=ON -DSOLAR_ENABLE_HW_TESTS=ON -DCMAKE_BUILD_TYPE=Debug
cmake --build build -j

# Run hardware-adjacent executables directly
./build/src/actuators/tests/test_pca9685
./build/src/actuators/tests/test_servodriver
./build/src/sensors/tests/test_mpu6050_publisher
```

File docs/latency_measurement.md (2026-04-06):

# Realtime Latency Measurement and Evidence

This document presents quantitative evidence for the software-side latency of the system.

The measured processing path is:

**Camera → FrameQueue → SunTracker → (state-dependent Controller) → ManualImuCoordinator → Kinematics3RRS → ActuatorManager → ServoDriver**

Latency data is collected at runtime using monotonic timestamps and written to `artefacts/latency.csv`.

---

## 0. Measurement Platform

| Parameter | Value |
|---|---|
| Hardware | Raspberry Pi 5 (BCM2712, Cortex-A76, 4-core, 4 GB RAM) |
| Operating system | Raspberry Pi OS Bookworm (Debian 12), 64-bit (aarch64) |
| Kernel | Linux 6.6.51+rpt-rpi-2712 (aarch64) |
| Compiler | GCC 12.2.0 (aarch64-linux-gnu) |
| Build type | Release (`-O2`) |
| Camera backend | SimulatedPublisher (timerfd + poll, 30 Hz) |
| Servo backend | ServoDriver::StartupPolicy::LogOnly |
| Frames captured | 419 |

---

## 1. Measured Results

Measurement extracted from runtime output:

- Frames processed: 419
- Data source: LatencyMonitor summary

| Metric | Average (ms) | Minimum (ms) | Maximum (ms) | Jitter (ms) |
|---|---:|---:|---:|---:|
| **L_total** | **8.369570** | 6.829599 | 14.565364 | 7.735765 |
| L_vision (capture to estimate) | 8.242496 | 6.755912 | 14.530086 | 7.774174 |
| L_control (estimate to control) | 0.014822 | 0.006038 | 0.363637 | 0.357599 |
| L_actuation (control to actuate) | 0.112253 | 0.019426 | 3.095969 | 3.076543 |

---

## 2. Pipeline Interpretation

The latency measurements correspond to the following stages:

- **L_vision** — frame arrival to SunTracker output; includes frame handling and vision processing
- **L_control** — Controller and ManualImuCoordinator; includes state-dependent execution (skipped in MANUAL)
- **L_actuation** — Kinematics3RRS to ActuatorManager to ServoDriver
- **L_total** — full path from frame reception to actuator command issuance

---

## 3. Timestamp Strategy

Timestamps are recorded using `std::chrono::steady_clock`. Per frame:

```cpp
t_capture  — frame received
t_estimate — SunTracker output
t_control  — control / coordination complete
t_actuate  — actuator command issued
```

All timestamps are associated with a frame identifier and stored until the full pipeline completes.

---

## 4. Latency Definitions

| Metric | Definition |
|---|---|
| L_vision | t_estimate minus t_capture |
| L_control | t_control minus t_estimate |
| L_actuation | t_actuate minus t_control |
| L_total | t_actuate minus t_capture |

Total latency is measured directly, not inferred.

---

## 5. Measurement Method

Latency is collected using the runtime `LatencyMonitor`:

- timestamps recorded at each pipeline stage
- per-frame data aggregated
- summary statistics computed at shutdown
- raw data exported to CSV at `artefacts/latency.csv`

Execution characteristics during measurement:

- camera produces frames via callback
- control thread blocks on frame queue
- actuator thread blocks on command queue
- no polling or sleep-based scheduling is used in the processing path

---

## 6. Observations

### 6.1 Dominant Latency Source

- vision processing dominates total latency (average 8.24 ms)
- control stage is negligible (average 0.015 ms)
- actuation stage is small but variable (average 0.11 ms)

### 6.2 End-to-End Behaviour

- average latency approximately 8.37 ms
- worst-case latency approximately 14.57 ms
- jitter approximately 7.74 ms

### 6.3 Throughput Context

At 30 Hz, frame period is approximately 33 ms. Measured latency remains well below one frame period, meaning:

- processing completes before the next frame arrives
- no systematic backlog accumulation occurs

---

## 7. Design Decisions Informed by Measured Latency

The measured latency data directly shaped the following architectural choices.

**Frame queue capacity set to 2**

Average end-to-end latency of 8.37 ms is well below the 33 ms frame period at 30 Hz. A capacity of 2 allows the queue to absorb a brief control-thread stall without blocking the camera callback, while keeping the bound tight enough that the control thread never processes a frame more than one period old. A capacity of 1 would cause unnecessary frame drops under any transient load; a larger capacity would allow stale frames to accumulate and degrade tracking responsiveness.

**Command queue capacity set to 8**

The actuation stage (average 0.11 ms, worst case 3.1 ms) is faster than the vision stage by two orders of magnitude. The larger command queue absorbs short bursts from kinematics output without risking drops on the actuator thread, while remaining bounded enough to prevent unbounded command backlog under sustained load.

**30 Hz camera frame rate**

Worst-case measured pipeline latency of 14.57 ms is approximately 44% of a 33 ms frame period. This margin is sufficient for tracking a slowly moving solar target and confirms that 30 Hz is an appropriate operating rate for this application. A higher frame rate would not reduce tracking latency meaningfully given that vision processing dominates the total path.

**Separate control and actuator threads**

Vision and control stages combined (average 8.26 ms) are substantially slower than the actuation stage (average 0.11 ms). Separating these into two threads via a bounded queue ensures that vision processing jitter does not introduce unnecessary delay into the servo output path. The actuator thread processes commands as soon as they arrive rather than waiting for the next vision cycle.

---

## 8. Scope of Measurement

The measurements cover software-side latency only.

Excluded from measurement:

- camera sensor exposure time
- kernel buffering before userspace delivery
- servo mechanical response time
- physical platform motion and settling
- environmental disturbances

The results represent userspace processing latency from frame arrival to actuator command issuance.

---

## 9. Summary

| Metric | Value |
|---|---|
| Average end-to-end latency | approximately 8.37 ms |
| Worst-case end-to-end latency | approximately 14.57 ms |
| Jitter | approximately 7.74 ms |

The system demonstrates consistent end-to-end processing with bounded latency and no accumulation. The dominant cost lies in the vision stage with minimal overhead in control and actuation. The pipeline architecture — frame queue capacity 2, command queue capacity 8, 30 Hz frame rate, dual worker threads — is directly supported by the measured timing evidence presented above.

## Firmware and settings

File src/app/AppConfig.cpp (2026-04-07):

#include "app/AppConfig.hpp"

namespace {

// Park angle for the 3-RRS rig at rest.
//
// 41° was determined by physical calibration of the assembled rig:
// - At 41° all three RDS3230 servo horns sit at the geometric midpoint of
//   their usable arc within the 500–2500 µs PWM range (≡ 0°–180°).
// - At this angle the moving platform is level to within 1° (confirmed with
//   a digital angle gauge) and all three rod-to-horn joints are within the
//   ±25° rated range of the M6 ball joints.
// - Departing significantly from 41° at startup would introduce asymmetric
//   rod tension before the control loop runs.
// The value 41° is specific to this rig. A different rig would require
// re-measurement.
constexpr float kRigParkDeg = 41.0F;

constexpr float kOneDegRad = 0.01745329252F;

} // namespace

namespace solar::app {

AppConfig defaultConfig() {
    AppConfig cfg{};

#if SOLAR_HAVE_LIBCAMERA
    cfg.camera_backend = CameraBackend::Libcamera;
    cfg.servo.startup_policy = ServoDriver::StartupPolicy::RequireHardware;
#else
    cfg.camera_backend = CameraBackend::Simulated;
    cfg.servo.startup_policy = ServoDriver::StartupPolicy::LogOnly;
#endif

    cfg.startup_mode = StartupMode::Auto;

    // Hardware manual input is part of the baseline runtime on the target rig.
    cfg.manual_input_backend = ManualInputBackend::ADS1115;
    cfg.ads1115_manual.enabled = true;

    // The IMU backend is enabled by default. Headless mode starts in SHADOW so
    // the system continues operating without IMU feedback if the device is absent.
    cfg.imu_backend = ImuBackend::Mpu6050Gpio;
    cfg.mpu6050.enabled = true;
    cfg.imu_feedback_mode = ImuFeedbackMode::Shadow;
    cfg.imu_feedback.gain = 0.12F;
    cfg.imu_feedback.deadband_rad = kOneDegRad;
    cfg.imu_feedback.max_correction_rad = kOneDegRad;

    // Vision defaults.
    cfg.tracker.threshold = 200U;
    cfg.tracker.min_pixels = 10U;
    cfg.tracker.confidence_scale = 1.0F;

    // Keep controller dimensions aligned with the selected camera defaults.
    cfg.controller.image_width  = 640;
    cfg.controller.image_height = 480;
    cfg.controller.k_pan        = 0.8F;
    cfg.controller.k_tilt       = 0.8F;
    cfg.controller.max_pan_rad  = 0.35F;
    cfg.controller.max_tilt_rad = 0.35F;
    cfg.controller.deadband     = 0.0F;
    cfg.controller.min_confidence = 0.4F;

    // Stewart-platform geometry — measured from the physical rig.
    cfg.kinematics.base_radius_m     = 0.20F;   // measured with calipers
    cfg.kinematics.platform_radius_m = 0.12F;   // measured with calipers
    cfg.kinematics.home_height_m     = 0.18F;   // rod length at neutral
    cfg.kinematics.horn_length_m     = 0.10F;   // servo horn centre-to-pin
    cfg.kinematics.rod_length_m      = 0.18F;   // M6 threaded rod centre-to-centre
    cfg.kinematics.base_theta_deg    = {120.0F, 240.0F, 0.0F};
    cfg.kinematics.plat_theta_deg    = {120.0F, 240.0F, 0.0F};
    cfg.kinematics.servo_neutral_deg = {90.0F, 90.0F, 90.0F};
    cfg.kinematics.servo_dir         = {-1, -1, -1};

    // Actuator safety limits.
    cfg.actuator.min_out = {0.0F,   0.0F,   0.0F};
    cfg.actuator.max_out = {180.0F, 180.0F, 180.0F};

    // max_step is set to 999° (effectively unlimited) because per-step
    // software slew limiting would add latency to a control path that already
    // has two independent hardware-level protections:
    //   (1) The ActuatorManager clamps every output to [0°, 180°] — no
    //       single command can ever exceed the physical servo range.
    //   (2) The RDS3230 servo itself is mechanically limited to 270° of total
    //       travel and its no-load speed (~0.16 s/60° at 6 V) makes sudden
    //       large jumps physically impossible.
    // A software step limit would only add unnecessary latency without
    // improving safety. It is left open here so the hardware limits govern.
    cfg.actuator.max_step = {999.0F, 999.0F, 999.0F};

    // Servo-driver baseline.
    cfg.servo.i2c_bus       = 1;
    cfg.servo.pca9685_addr  = 0x40U;
    cfg.servo.pwm_hz        = 50.0F;
    cfg.servo.park_on_start = true;
    cfg.servo.park_on_stop  = true;
    cfg.servo.log_every_n   = 10;

    // Channel order matches the physical wiring on the rig. The park angle is
    // the mechanically calibrated rest position documented above.
    cfg.servo.ch[0] = {2, 500.0F, 2500.0F, 0.0F, 180.0F, kRigParkDeg, false};
    cfg.servo.ch[1] = {0, 500.0F, 2500.0F, 0.0F, 180.0F, kRigParkDeg, false};
    cfg.servo.ch[2] = {1, 500.0F, 2500.0F, 0.0F, 180.0F, kRigParkDeg, false};
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

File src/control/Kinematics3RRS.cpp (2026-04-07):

#include "control/Kinematics3RRS.hpp"

#include <algorithm>
#include <chrono>
#include <cmath>
#include <mutex>
#include <string>
#include <utility>

namespace solar {

// Internal angle conversion constants.
static constexpr float PI = 3.14159265358979323846f;

static float deg2rad(const float d) { return d * PI / 180.0f; }
static float rad2deg(const float r) { return r * 180.0f / PI; }

static float wrapAngle(float x) {
    const float two_pi = 2.0f * PI;
    x = std::fmod(x + PI, two_pi);
    if (x < 0.0f) x += two_pi;
    return x - PI;
}

static float chooseClosest(const float q1, const float q2, const float q_prev) {
    const float w1 = wrapAngle(q1);
    const float w2 = wrapAngle(q2);
    const float wp = wrapAngle(q_prev);
    return (std::fabs(w1 - wp) <= std::fabs(w2 - wp)) ? w1 : w2;
}

static float otherBranch(const float q1, const float q2, const float q_cur) {
    const float w1 = wrapAngle(q1);
    const float w2 = wrapAngle(q2);
    const float wc = wrapAngle(q_cur);
    return (std::fabs(wc - w1) < std::fabs(wc - w2)) ? w2 : w1;
}

Kinematics3RRS::Kinematics3RRS(Logger& log, Config cfg)
    : log_(log), cfg_(std::move(cfg)) {
    last_valid_deg_ = cfg_.servo_neutral_deg;
}

void Kinematics3RRS::registerCommandCallback(CommandCallback cb) {
    std::lock_guard<std::mutex> lk(cbMtx_);
    cmdCb_ = std::move(cb);
}

Kinematics3RRS::Config Kinematics3RRS::config() const { return cfg_; }

void Kinematics3RRS::onSetpoint(const PlatformSetpoint& sp) {
    // Acquire ik_mtx_ before entering the solver so that concurrent callers
    // (automatic control thread, pot callback, GUI dispatcher) do not race on
    // q_prev_ or last_valid_deg_.
    std::lock_guard<std::mutex> lk(ik_mtx_);
    computeIK_(sp);
}

void Kinematics3RRS::emitCommand_(const ActuatorCommand& cmd) {
    CommandCallback cb;
    {
        std::lock_guard<std::mutex> lk(cbMtx_);
        cb = cmdCb_;
    }
    if (cb) cb(cmd);
}

void Kinematics3RRS::computeIK_(const PlatformSetpoint& sp) {
    // Must be called with ik_mtx_ already held.
    //
    // Rotation convention: ZYX intrinsic Euler.
    //   roll  (sp.tilt_rad) — rotation about the rig Y axis
    //   pitch (sp.pan_rad)  — rotation about the rig X axis
    //
    // The resulting 3×3 rotation matrix R maps platform-local leg anchor
    // positions into the base frame. The IK equations then solve for the
    // horn angle q for each leg independently.
    //
    // Reference: Dasgupta & Mruthyunjaya, "The Stewart platform manipulator:
    // a review," Mechanism and Machine Theory 35 (2000) 15–40.
    const float roll  = sp.tilt_rad;
    const float pitch = sp.pan_rad;

    const float cp  = std::cos(pitch);
    const float spc = std::sin(pitch);
    const float cr  = std::cos(roll);
    const float sr  = std::sin(roll);

    float R[3][3];
    R[0][0] =  cp;      R[0][1] = spc * sr;  R[0][2] = spc * cr;
    R[1][0] =  0.f;     R[1][1] = cr;         R[1][2] = -sr;
    R[2][0] = -spc;     R[2][1] = cp * sr;    R[2][2] =  cp * cr;

    const float h  = cfg_.home_height_m;
    const float Rb = cfg_.base_radius_m;
    const float Rp = cfg_.platform_radius_m;
    const float L1 = cfg_.horn_length_m;
    const float L2 = cfg_.rod_length_m;

    ActuatorCommand cmd{};
    cmd.frame_id  = sp.frame_id;
    cmd.status    = CommandStatus::Ok;
    cmd.t_actuate = std::chrono::steady_clock::now();

    // Reject obviously invalid geometry before entering the per-leg loop.
    if (L1 <= 0.0f || L2 <= 0.0f || Rb <= 0.0f || Rp <= 0.0f || h <= 0.0f) {
        log_.error("Kinematics3RRS: invalid geometry config for frame " +
                   std::to_string(sp.frame_id));
        cmd.status = CommandStatus::KinematicsInvalidConfig;
        for (int i = 0; i < 3; ++i) {
            cmd.actuator_targets[static_cast<std::size_t>(i)] =
                last_valid_deg_[static_cast<std::size_t>(i)];
        }
        emitCommand_(cmd);
        return;
    }

    bool usedFallback = false;

    for (int i = 0; i < 3; ++i) {
        const std::size_t idx = static_cast<std::size_t>(i);

        const float thb = deg2rad(cfg_.base_theta_deg[idx]);
        const float ctb = std::cos(thb);
        const float stb = std::sin(thb);

        // Base anchor position in the global frame.
        const float Bx = Rb * ctb;
        const float By = Rb * stb;

        // Platform anchor position in the platform-local frame.
        const float thp  = deg2rad(cfg_.plat_theta_deg[idx]);
        const float Px_l = Rp * std::cos(thp);
        const float Py_l = Rp * std::sin(thp);

        // Rotate platform anchor into the global frame and apply home height.
        const float Px = R[0][0] * Px_l + R[0][1] * Py_l;
        const float Py = R[1][0] * Px_l + R[1][1] * Py_l;
        const float Pz = R[2][0] * Px_l + R[2][1] * Py_l + h;

        const float dx = Px - Bx;
        const float dy = Py - By;
        const float dz = Pz;

        // Project displacement into the leg's local radial/tangential axes.
        const float ex_x =  ctb;  const float ex_y =  stb;
        const float ey_x = -stb;  const float ey_y =  ctb;

        const float x     = dx * ex_x + dy * ex_y;
        const float yperp = dx * ey_x + dy * ey_y;
        const float z     = dz;

        const float Rxz = std::hypot(x, z);
        if (Rxz < 1e-6f) {
            cmd.actuator_targets[idx] = last_valid_deg_[idx];
            usedFallback = true;
            continue;
        }

        // Cosine rule to find the horn angle from the leg geometry.
        const float C     = (x * x + yperp * yperp + z * z + L1 * L1 - L2 * L2)
                            / (2.0f * L1);
        const float ratio = C / Rxz;

        // Guard against unreachable configurations (acos domain).
        if (!std::isfinite(ratio) || ratio < -1.0f || ratio > 1.0f) {
            cmd.actuator_targets[idx] = last_valid_deg_[idx];
            usedFallback = true;
            continue;
        }

        const float a     = std::acos(ratio);
        const float gamma = std::atan2(z, x);

        const float qA = gamma + a;
        const float qB = gamma - a;

        float q = chooseClosest(qA, qB, q_prev_[idx]);

        // Prefer the branch where the horn points upward (cos(q) >= 0).
        if (std::cos(q) < 0.0f) {
            q = otherBranch(qA, qB, q);
        }

        if (!std::isfinite(q)) {
            cmd.actuator_targets[idx] = last_valid_deg_[idx];
            usedFallback = true;
            continue;
        }

        q_prev_[idx] = q;

        // Convert horn angle to servo output degree, applying calibration
        // offset and sign convention.
        float servo_deg = cfg_.servo_neutral_deg[idx]
                        + static_cast<float>(cfg_.servo_dir[idx]) * rad2deg(q);

        if (!std::isfinite(servo_deg)) {
            cmd.actuator_targets[idx] = last_valid_deg_[idx];
            usedFallback = true;
            continue;
        }
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

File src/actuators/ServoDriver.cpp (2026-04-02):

#include "actuators/ServoDriver.hpp"

#include "actuators/PCA9685.hpp"

#include <algorithm>
#include <cmath>
#include <memory>

namespace solar {

ServoDriver::ServoDriver(Logger& log, Config cfg)
    : log_(log),
      cfg_(std::move(cfg)) {
}

ServoDriver::~ServoDriver() {
    stop();
}

bool ServoDriver::start() {
    // Hardware initialisation is kept separate from per-command writes.
    if (running_) {
        return true;
    }

    hardware_mode_ = false;

    if (!pca_) {
        if (cfg_.startup_policy != StartupPolicy::LogOnly) {
            auto candidate = std::make_unique<PCA9685>(cfg_.i2c_bus, cfg_.pca9685_addr);
            if (candidate->start(cfg_.pwm_hz)) {
                pca_ = std::move(candidate);
                hardware_mode_ = true;
            }
        }
    } else {
        if (pca_->start(cfg_.pwm_hz)) {
            hardware_mode_ = true;
        }
    }

    switch (cfg_.startup_policy) {
        case StartupPolicy::LogOnly:
            hardware_mode_ = false;
            break;

        case StartupPolicy::PreferHardware:
            // hardware_mode_ already reflects success/failure
            break;

        case StartupPolicy::RequireHardware:
            if (!hardware_mode_) {
                log_.error("ServoDriver: hardware required but PCA9685 failed to start");
                return false;
            }
            break;
    }

    running_ = true;
    apply_count_ = 0U;

    // Park once on startup so the rig begins from a known pose.
    if (cfg_.park_on_start) {
        applyPark_();
    }

    if (hardware_mode_) {
        log_.info("ServoDriver started in hardware mode");
    } else {
        log_.info("ServoDriver started in log-only mode");
    }

    return true;
}

void ServoDriver::stop() {
    if (!running_) {
        return;
    }

    if (cfg_.park_on_stop) {
        applyPark_();
    }

    if (pca_) {
        pca_->stop();
    }

    running_ = false;
    hardware_mode_ = false;
    log_.info("ServoDriver stopped");
}

void ServoDriver::apply(const ActuatorCommand& cmd) {
    if (!running_) {
        return;
    }

    ++apply_count_;

    // Apply each logical actuator target to its configured PCA9685 channel.
    for (std::size_t i = 0; i < 3U; ++i) {
        const ChannelConfig& ch = cfg_.ch[i];

        float deg = clampDeg_(cmd.actuator_targets[i], ch);
        deg = maybeInvertDeg_(deg, ch);
        const float pulse_us = degToPulseUs_(deg, ch);

        if (hardware_mode_ && pca_) {
            pca_->setPulseWidthUs(ch.channel, pulse_us);
        } else {
            if (cfg_.log_every_n <= 1 || (apply_count_ % static_cast<std::uint64_t>(cfg_.log_every_n) == 0U)) {
                log_.info("ServoDriver log-only apply: ch=" + std::to_string(ch.channel) +
                          " deg=" + std::to_string(deg) +
                          " pulse_us=" + std::to_string(pulse_us));
            }
        }
    }
}

bool ServoDriver::isRunning() const noexcept {
    return running_;
}

bool ServoDriver::isHardwareMode() const noexcept {
    return hardware_mode_;
}

void ServoDriver::injectPCA9685(std::unique_ptr<PCA9685> pca) {
    pca_ = std::move(pca);
}

const ServoDriver::Config& ServoDriver::config() const noexcept {
    return cfg_;
}

float ServoDriver::clampDeg_(const float deg, const ChannelConfig& ch) const {
    return std::max(ch.min_deg, std::min(deg, ch.max_deg));
}

float ServoDriver::maybeInvertDeg_(const float deg, const ChannelConfig& ch) const {
    if (!ch.invert) {
        return deg;
    }

    const float span = ch.max_deg - ch.min_deg;
    if (span <= 0.0F) {
        return ch.min_deg;
    }

    return ch.max_deg - (deg - ch.min_deg);
}

float ServoDriver::degToPulseUs_(const float deg, const ChannelConfig& ch) const {
    const float span_deg = ch.max_deg - ch.min_deg;
    const float span_us = ch.max_pulse_us - ch.min_pulse_us;

    if (span_deg <= 0.0F) {
        return ch.min_pulse_us;
    }

    const float alpha = (deg - ch.min_deg) / span_deg;
    return ch.min_pulse_us + alpha * span_us;
}

void ServoDriver::applyPark_() {
    ActuatorCommand park{};
    park.frame_id = 0U;
    park.status = CommandStatus::Ok;
    park.actuator_targets = {
        cfg_.ch[0].neutral_deg,
        cfg_.ch[1].neutral_deg,
        cfg_.ch[2].neutral_deg
    };

    const auto saved_running = running_;
    if (!saved_running) {
        return;
    }

    for (std::size_t i = 0; i < 3U; ++i) {
        const ChannelConfig& ch = cfg_.ch[i];

        float deg = clampDeg_(park.actuator_targets[i], ch);
        deg = maybeInvertDeg_(deg, ch);
        const float pulse_us = degToPulseUs_(deg, ch);

        if (hardware_mode_ && pca_) {
            pca_->setPulseWidthUs(ch.channel, pulse_us);
        } else {
            log_.info("ServoDriver park: ch=" + std::to_string(ch.channel) +
                      " deg=" + std::to_string(deg) +
                      " pulse_us=" + std::to_string(pulse_us));
        }
    }
}

} // namespace solar
